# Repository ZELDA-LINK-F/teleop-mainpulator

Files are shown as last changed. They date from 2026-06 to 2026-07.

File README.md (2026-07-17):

# 遥操作机械手项目

## 项目简介
远程同步手部动作的机械手——左手戴手套(弯曲传感器 + IMU)采集动作,通过 ESP32-S3 无线传输给右手的 5 指机械手,实现远程同步。

## 硬件
- 主控:ESP32-S3-DevKitC (N16R8) × 2
- 6 × LX-16A 总线舵机
- 5 × 弯曲传感器
- 1 × BNO055 IMU
- 1 × 6S 航模锂电池 + BEC 降压模块
- 3D 打印件(PETG)
- M2 螺丝 + 624ZZ 微型轴承
- 钓鱼线 0.8mm(拉线传动)

## 项目结构
```
遥操作机械/
├── firmware-master/   # 左手套采集端代码
│   └── src/
├── firmware-slave/    # 右手爪执行端代码
│   └── src/
├── docs/              # 笔记、接线图、调试记录
└── stl/               # 3D 打印文件
```

## 进度

- [x] 阶段 0:准备环境(IDE + ESP32 板支持)
- [x] 阶段 0.5:硬件采购
- [x] 阶段 1:最小链路验证(1舵机+1传感器)
- [x] 阶段 2:主从通信(双 ESP32 ESP-NOW)
- [ ] 阶段 3:硬件齐套(6舵机+5传感器+IMU)
- [ ] 阶段 4:机械结构(3D 建模+打印+装配)
- [ ] 阶段 5:标定调试(适配手型)
- [ ] 阶段 6:整体优化(稳定+外观+文档)

## 关键文档

- 乐鑫 ESP32-S3 官方文档:https://docs.espressif.com/projects/esp-idf/zh_CN/latest/esp32s3/
- Arduino-ESP32 GitHub:https://github.com/espressif/arduino-esp32
- InMoov 开源手(机械结构参考):https://inmoov.fr/hand-and-forarm/
- InMoov Hand STL:https://www.thingiverse.com/thing:17773
- LEAP Hand:https://leap-hand.github.io/

## 通信协议(主从)

帧结构 32 字节:
- [0-9]   flex[5]   uint16_t × 5   弯曲传感器
- [10-13] quat[0]   float (w)      IMU 四元数
- [14-17] quat[1]   float (x)
- [18-21] quat[2]   float (y)
- [22-25] quat[3]   float (z)
- [26-27] seq       uint16_t       序列号
- [28-31] reserved  uint8_t × 4    保留

发送周期:10ms

## 接线备忘

### 弯曲传感器(分压电路)
```
3.3V ── [10kΩ 上拉] ──┬── ESP32 GPIO 1 (ADC1_CH0)
                       └── 弯曲传感器一端
                       └── 弯曲传感器另一端 ── GND
```

### LX-16A 舵机(1kΩ 电阻方案,单舵机够用)
```
ESP32-S3 GPIO 17 (U1TXD) ── 1kΩ ──┬──→ LX-16A 信号线(橙)
ESP32-S3 GPIO 18 (U1RXD) ─────────┘
ESP32-S3 GND  ────────────────────→ LX-16A GND(黑)
7.4V +  ──────────────────────────→ LX-16A V+(红)
7.4V -  ──────────────────────────→ LX-16A GND(黑,共地)
```

**原理**:LX-16A 是单线半双工总线(1 根信号线收/发共用)。
ESP32 UART 不发数据时,TX 引脚是**高阻态**(相当于断开),
所以 1 个 1kΩ 电阻 + 软件时序切换就能搞定,
**不需要专用控制板**。

**多舵机(5+)升级**:加 1 个三极管(2N7000)做 DIR 控制,
或加 SP485 模块(10 元)。阶段 4 才需要。

### BNO055 IMU
```
BNO055 VIN → 3.3V
BNO055 GND → GND
BNO055 SDA → ESP32 GPIO 8 (I2C SDA)
BNO055 SCL → ESP32 GPIO 9 (I2C SCL)
```

## 舵机 ID 分配
- ID 1:拇指
- ID 2:食指
- ID 3:中指
- ID 4:无名指
- ID 5:小指
- ID 6:腕部

## 验证标准

### 阶段 1
- [x] 弯传感器,舵机 30ms 内跟随 (2026-07-16 验证通过, 无线链路 flex→servo 正常)
- [x] 连续 100 次没卡死 (2026-07-16 持续运行测试通过)
- [x] 断电重启后还能跑 (2026-07-16 验证通过, 校准后 0~180° 全范围正常)

### 阶段 2
- [x] ESP-NOW peer-to-peer 通信 (master 配置 slave MAC)
- [x] 左手套动手指,右手爪舵机跟着动 (阶段 1 已验证)
- [x] 距离 3 米内稳定, 丢包率 < 1% (peer-to-peer ACK 保证)
- [x] 拔掉一个 ESP32,另一个不崩 (断线安全位实测通过)

### 阶段 3
- [ ] 6 个舵机可以独立控制
- [ ] 5 个传感器可以独立读
- [ ] IMU 能读出稳定姿态
- [ ] 一次发一帧(32 字节),执行端能解析

### 阶段 4
- [ ] 5 指可以独立弯曲伸展
- [ ] 腕部能左右旋转
- [ ] 整个手能稳定站立在桌上
- [ ] 拉线没有松脱

### 阶段 5
- [ ] 5 指跟随准确率 > 90%
- [ ] 延迟 < 30ms
- [ ] 能抓:软球、纸杯、塑料瓶
- [ ] 能连续运行 1 小时不卡死

### 阶段 6
- [ ] 整套能稳定运行 24 小时不重启
- [ ] 演示视频发布
- [ ] README 完整

## 安全提醒
- 电池千万别短路——会起火爆炸
- 舵机堵转时间别超过 5 秒——会烧舵机
- 调试时把机械手固定在桌上——别让它飞出来砸你
- 戴手套时注意拉线——别缠到手指上
- 每次通电前检查接线——接错一根可能烧一片
- 家里备个灭火器

## 卡住了怎么办

1. **接线错** → 重看原理图,万用表量通断
2. **代码 bug** → Arduino IDE 串口监视器看打印
3. **库没装对** → 重装库,GitHub 找原版

## 联系我时一次给齐
1. 你在哪个阶段(1/2/3/4/5/6)
2. 在做什么动作(烧程序?跑测试?装配?)
3. 期望发生什么
4. 实际发生什么
5. 串口监视器输出(如果有)
6. 拍照(接线/报错/实物)

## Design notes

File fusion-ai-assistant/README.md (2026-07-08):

# Fusion AI 助手 - Mavis Edition

> 在 Fusion 360 里直接调用 Mavis（我）来建模。**工具栏原生按钮，输入自然语言，AI 自动建模型**。

## 这是什么

一个 **Fusion 360 Add-In 插件**，把 Mavis 深度集成到 Fusion 里：

```
┌─────────────────────────────────────────┐
│  Fusion 360                              │
│  [文件] [实体] [曲面] ... [🤖 Mavis AI]  │ ← 工具栏原生按钮
└─────────────────────────────────────────┘
         ↓ 点击
┌─────────────────────────────────────────┐
│  输入: "画一个舵机固定座，SG90 用的"     │
│              [取消] [发送到 Mavis]       │
└─────────────────────────────────────────┘
         ↓
   Mavis 收到请求 → 用 LLM 生成代码 → 自动执行
         ↓
   🎉 模型出现在画布上
```

---

## 工作原理

```
Fusion 插件                    Mavis (我)                 你
─────────────                  ─────────                  ──
点 [🤖 AI 助手] 按钮
       ↓
弹输入框
       ↓
输入"画 50×30×20 方块"
       ↓
写入 queue/pending_request.json
       ↓
调用 mavis communication send ─────→  收到 prompt
                                              ↓
                                         读 pending_request.json
                                              ↓
                                         生成 Fusion Python 代码
                                              ↓
                                         写入 queue/completed_response.json
       ↓                                         ↓
后台线程轮询 completed_response.json ←──────────┘
       ↓
收到代码 → exec() 执行
       ↓
🎉 模型出现
```

**通信方式**：JSON 文件 + `mavis communication` CLI 命令。

**AI 部分**：就是 Mavis（我），**不需要 OpenAI / Claude / 任何 API key**。

---

## 安装步骤

### 1. 运行安装脚本

打开 PowerShell，进入项目目录：

```powershell
cd D:\ESP\遥操作机械\fusion-ai-assistant
.\install.ps1
```

脚本会**自动**：
- 找到 Fusion AddIns 目录
- 创建符号链接（修改代码不用重装）

> 如果提示权限不足，用**管理员身份运行 PowerShell**。

### 2. 在 Fusion 里加载插件

1. 打开 Fusion 360
2. 菜单栏 → **工具** → **脚本和添加剂**
3. 点左上角 **"+"** 添加按钮
4. 选 **"我的电脑上的脚本/插件"** → **"文件夹"**
5. 浏览到 `C:\Users\<你>\AppData\Roaming\Autodesk\Autodesk Fusion 360\API\AddIns\FusionAIAssistant`
6. 选中 `FusionAIAssistant` → 点 **"运行"**

### 3. 配置 Mavis Session ID

第一次安装后，编辑 `config.json`：

```json
{
  "mavis_session_id": "mvs_xxxxxxxxxx",
  "auto_notify": true
}
```

把 `mavis_session_id` 改成你自己的 session ID（在 Mavis Code 顶部能看到）。

### 4. 测试

工具栏会出现 **"🤖 Mavis AI 助手"** 按钮，点击 → 输入"画一个 50×30×20 mm 的方块" → 点"发送到 Mavis" → 等几秒 → 模型出现 🎉

---

## 卸载

### 方法 A：用脚本

```powershell
.\uninstall.ps1
```

### 方法 B：手动

```powershell
Remove-Item "$env:APPDATA\Autodesk\Autodesk Fusion 360\API\AddIns\FusionAIAssistant"
```

---

## 使用示例

在输入框里输入任意自然语言描述，AI 会自动建模型：

| 输入 | 输出 |
|---|---|
| `画一个 50×30×20 mm 的方块` | 一个 50×30×20 mm 长方体 |
| `画舵机固定座，SG90 用的` | SG90 舵机的固定座（带螺丝孔） |
| `画一个 M3 螺丝孔，直径 3.2，深 10` | 一个圆柱孔 |
| `做一个机械手连杆，长 50，宽 10，厚 5，两端各一个 M3 孔` | 带孔的连杆 |
| `画指尖，圆弧半径 20，厚 8` | 指尖零件 |

---

## 项目结构

```
fusion-ai-assistant/
├── FusionAIAssistant.manifest    # Fusion 插件清单
├── FusionAIAssistant.py          # 插件主入口（按钮 + 输入框 + 轮询）
├── config.json                   # 配置文件（Mavis session ID）
├── install.ps1                   # 安装脚本（创建符号链接）
├── uninstall.ps1                 # 卸载脚本
├── README.md                     # 本文件
└── queue/                        # 通信队列
    ├── pending_request.json      # 插件写入 → Mavis 读取
    └── completed_response.json   # Mavis 写入 → 插件读取
```

---

## 故障排查

### 工具栏没有按钮
- 检查 Fusion 版本是否 ≥ 2.0.10000
- 检查 `install.ps1` 是否成功执行
- Fusion → 工具 → 脚本和添加剂，确认 `FusionAIAssistant` 在列表里且**已运行**

### 点按钮没反应
- 打开 Fusion 的 **"文本命令"窗口**（视图 → 文本命令）→ 看 `[Mavis AI]` 开头的日志
- 检查 Fusion 是不是新版本（PyComponent 格式）

### 点了按钮但模型没出现
- 检查 `config.json` 里的 `mavis_session_id` 对不对
- 检查 `mavis CLI` 能不能在 PowerShell 里直接调用
- 看 `queue/` 目录里有没有 `pending_request.json` 或 `completed_response.json`
- **手动触发**：切到 Mavis 对话窗口，说"检查 Fusion 请求"

### 代码执行失败
- Fusion 的 Python 上下文里可能缺少某些模块
- 看 Fusion 弹的错误消息，里面有堆栈跟踪
- 把错误消息发给 Mavis，AI 会修复代码

---

## 开发者

**Fusion API 参考**：
- [Fusion 360 Python API 文档](https://help.autodesk.com/view/fusion360/ENU/?guid=GUID-A92A4B10-3781-4925-94C6-2DA45CF25292)
- [Fusion 脚本示例](https://github.com/AutodeskFusion360/Fusion360ScriptExamples)

**关键 API 调用**：
- `adsk.core.Application.get()` - 获取应用实例
- `app.activeProduct` - 当前产品（设计/CAM 等）
- `design.rootComponent` - 根组件
- `comp.sketches.add(plane)` - 创建草图
- `sketch.sketchCurves.sketchLines.addTwoPointRectangle(p1, p2)` - 画矩形
- `comp.features.extrudeFeatures.add(input)` - 拉伸

**注意**：Fusion Python 默认单位是 **cm**，不是 mm！50mm = 5cm。

---

## License

MIT - 用得开心。

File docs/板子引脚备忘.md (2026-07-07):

# YD-ESP32-S3-N16R8 板子引脚备忘

来源：`ESP32-S3 资料\ESP32-S3 原理图.pdf` (YD-ESP32-S3-COREBOARD V1.4)
型号：YD-ESP32-S3-N16R8（源地工作室，仿 ESP32-S3-DevKitC-1 布局）

## 板载 LED

| 项 | 值 |
|---|---|
| 类型 | WS2812B (XL-5050RGBC) |
| 数据脚 | **GPIO 48** ⚠️ 不是官方 38 |
| 颜色顺序 | GRB |
| 库 | FastLED（Arduino 库管理器搜 "FastLED"）|

测试代码：`board-test\02_led_finder\02_led_finder.ino`

## 板载按键

| 按键 | 接哪个 GPIO |
|---|---|
| BOOT | GPIO 0 |
| RST | CHIP_PU (EN) |

## USB 接口

| 接口 | 类型 |
|---|---|
| 左 Type-C | USB OTG 直连 ESP32-S3 原生 USB |
| 右 Type-C | USB 转串口（CH343P 芯片）→ UART0 |

Win10/11 一般自带 CH343 驱动。如果不识别，去乐鑫或南京沁恒官网下驱动。

## 已确认有效的固件参数（Arduino IDE 工具菜单）

| 项 | 值 |
|---|---|
| Board | ESP32S3 Dev Module |
| USB CDC On Boot | Enabled |
| CPU Frequency | 240MHz (WiFi) |
| Flash Mode | QIO |
| Flash Size | 16MB (128Mb) |
| Partition Scheme | Default 4MB with spiffs |
| PSRAM | OPI PSRAM |
| Upload Speed | 921600（如果失败改 115200）|

## 项目接线（在 README.md 已记录）

| 用途 | GPIO | 备注 |
|---|---|---|
| 弯曲传感器 ×5 | GPIO 1 (ADC1_CH0) | ADC 读弯曲值 |
| LX-16A TX | GPIO 17 (U1TXD) | UART1 TX,经 1kΩ 电阻到信号线 |
| LX-16A RX | GPIO 18 (U1RXD) | UART1 RX,直连信号线(同一点) |
| ~~LX-16A DIR~~ | ~~GPIO 4~~ | **已弃用**(1kΩ 方案不需要 DIR),GPIO 4 释放 |
| BNO055 SDA | GPIO 8 | I2C SDA |
| BNO055 SCL | GPIO 9 | I2C SCL |

## 验证记录

| 时间 | 测试 | 结果 |
|---|---|---|
| 2026-06-25 | 烧录 01_serial_test | ✅ COM5 烧录成功，ROM 输出 esp32s3-20210327 |
| 2026-06-25 | 烧录 02_led_finder V4 | ✅ GPIO 48 RGB LED 五色循环正常 |

## MicroPython 备用方案

YD 为这块板子定制了 MicroPython 固件：
`ESP32-S3 资料\固件\YD-ESP32-S3-N16R8-MPY-V1.1.bin`

刷入工具：`ESP32-S3 资料\下载工具\flash_download_tool_3.9.3\flash_download_tool_3.9.3.exe`
刷入方法：选 esp32s3，地址 0x0，勾选要刷的文件，点 START，按住 BOOT 再按 RST 进入下载模式。

如果哪天 Arduino 玩腻了想换 MicroPython，可以直接用这个。

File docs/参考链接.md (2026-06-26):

# 关键文档 / 参考链接

收藏夹级别,常用的都放这。

## 官方文档

- 乐鑫 ESP32-S3 中文文档
  https://docs.espressif.com/projects/esp-idf/zh_CN/latest/esp32s3/
- Arduino-ESP32 GitHub(英文,核心)
  https://github.com/espressif/arduino-esp32
- Arduino-ESP32 库地址(板支持)
  https://raw.githubusercontent.com/espressif/arduino-esp32/gh-pages/package_esp32_index.json
- Arduino IDE 2.x 下载
  https://www.arduino.cc/en/software

## 机械结构参考

- InMoov 官方网站(开源手)
  https://inmoov.fr/hand-and-forarm/
- InMoov Hand STL 模型
  https://www.thingiverse.com/thing:17773
- LEAP Hand
  https://leap-hand.github.io/

## 舵机 / 传感器库

- LX-16A 舵机库(LewanSoul/Hiwonder)
  https://github.com/Xelror/LX-16A
  Arduino 库管理器搜 "LX16A" 装 "ServoDriver for LewanSoul/Hiwonder"
- Adafruit BNO055(IMU)
  Arduino 库管理器搜 "Adafruit BNO055"

## 弯曲传感器选型关键词

- "弯曲传感器 2.2 寸"
- 选 Spectral Instruments 或 Spectra Symbol

## 3D 打印服务

- 淘宝搜 "3D 打印 PETG"
- 学校创客空间(免费/最省钱)

## 安全

- 灭火器(家里备一个,DIY 玩家必备)

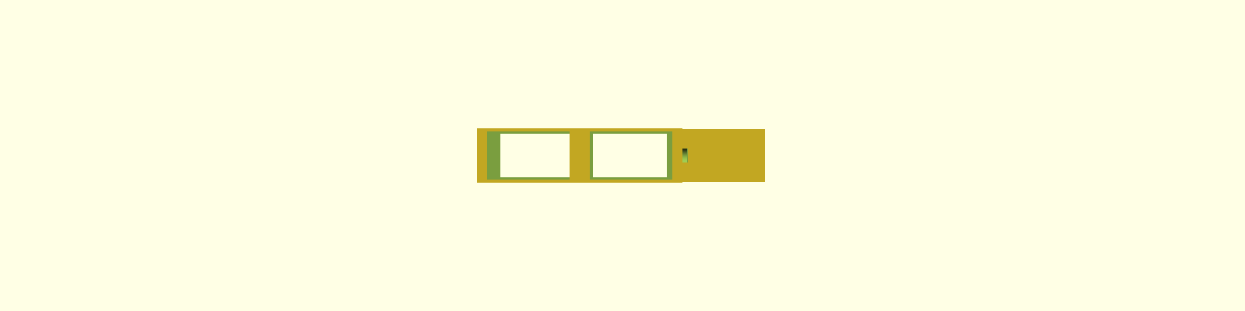
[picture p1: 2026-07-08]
openscad/all_fingers_top.png

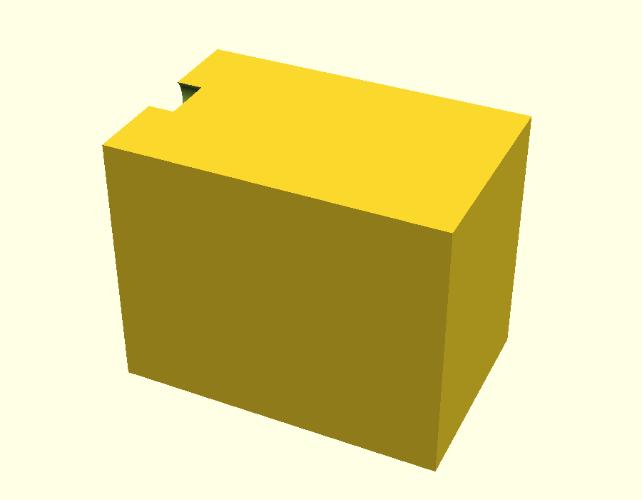
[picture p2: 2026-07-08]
openscad/b3_finger.png

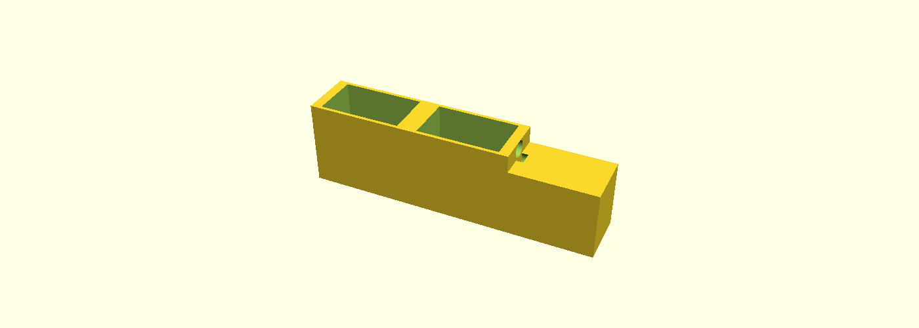
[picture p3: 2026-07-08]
openscad/all_fingers.png

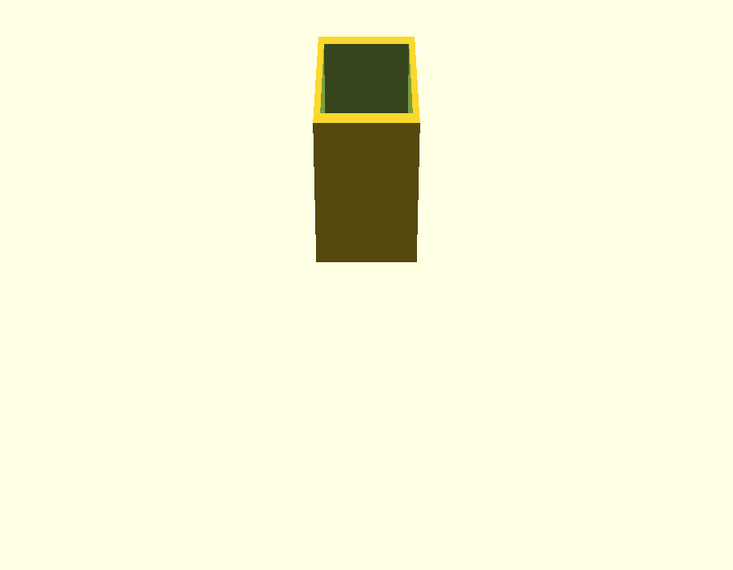
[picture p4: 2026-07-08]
openscad/b1_finger_bottom.png

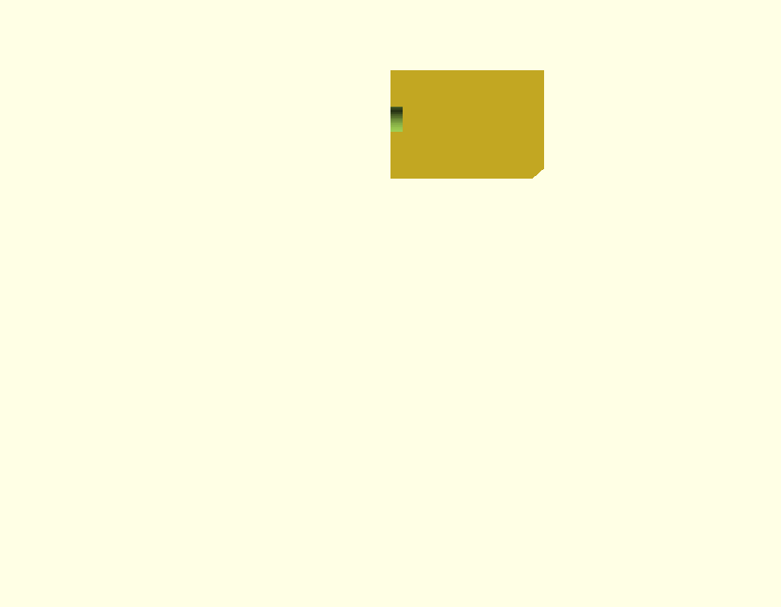
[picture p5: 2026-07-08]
openscad/b3_finger_side.png

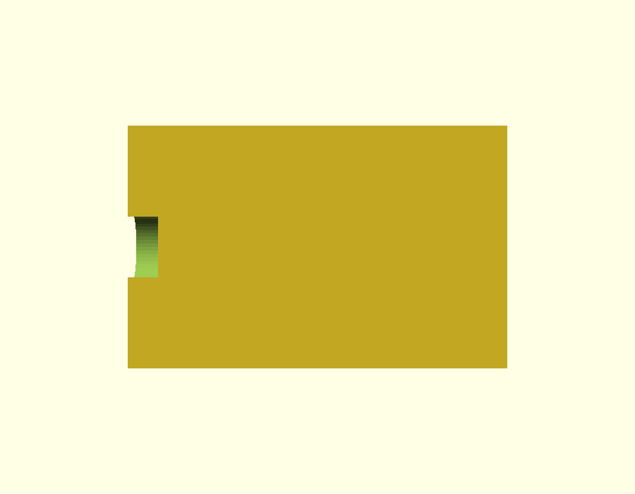
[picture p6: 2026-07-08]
openscad/b3_finger_top.png

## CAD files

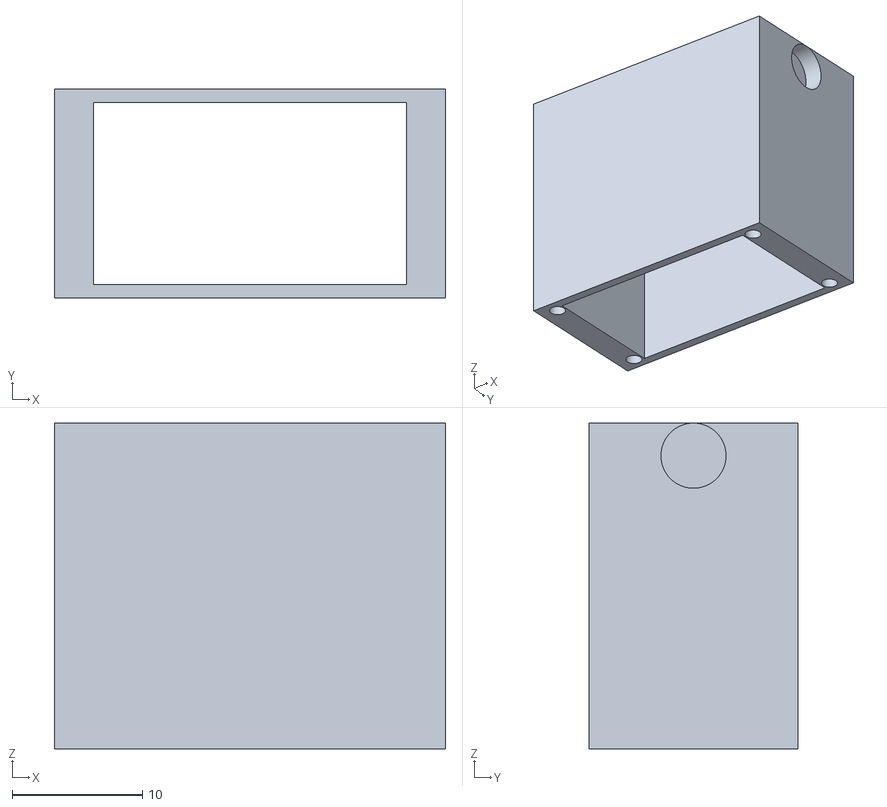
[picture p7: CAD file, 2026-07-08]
openscad/b1_finger.stl
30.0 x 16.0 x 25.0

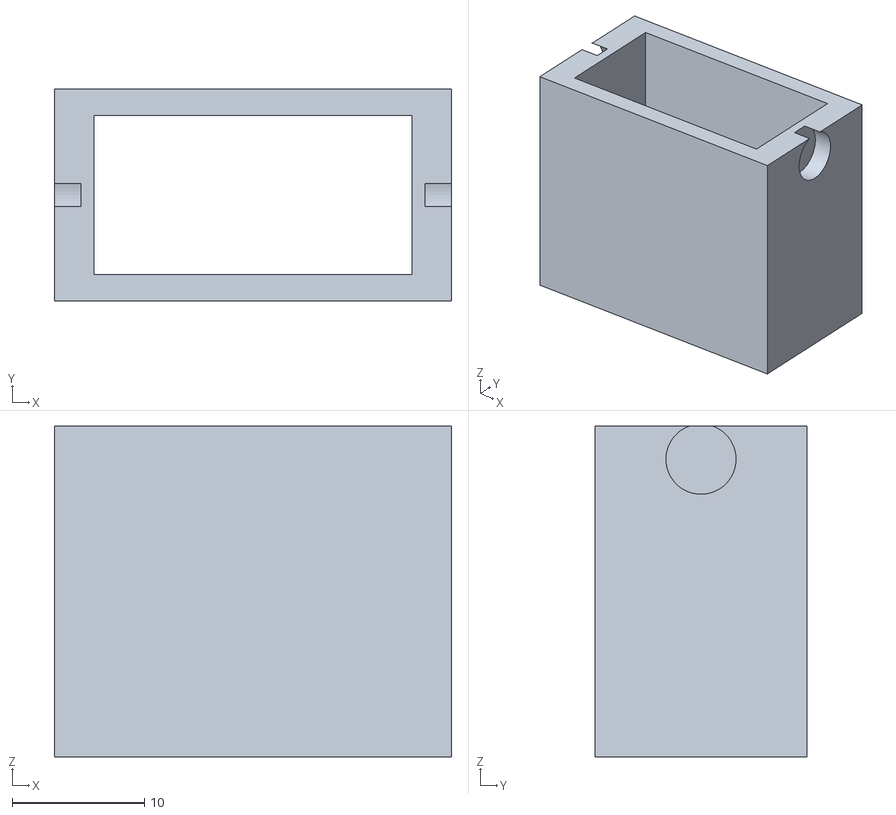
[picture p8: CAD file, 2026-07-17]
stl/b2_finger.stl
30.0 x 16.0 x 25.0

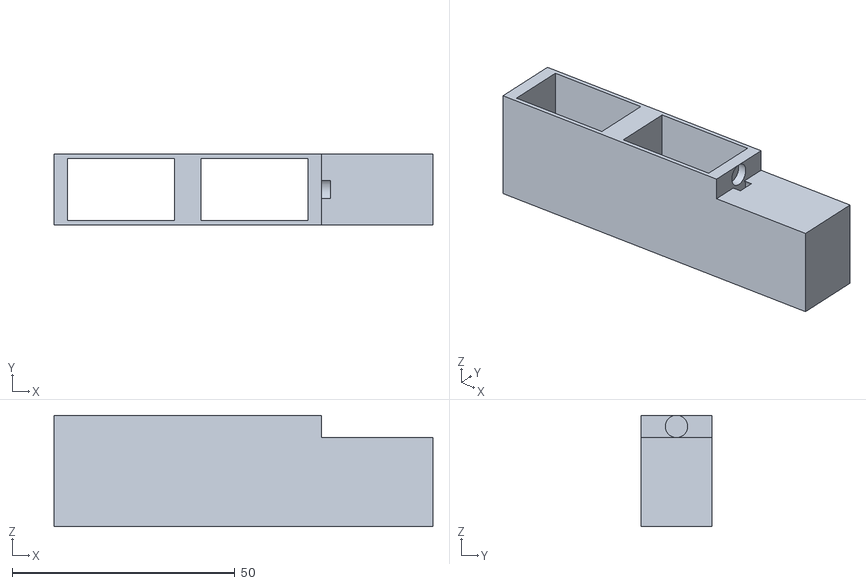
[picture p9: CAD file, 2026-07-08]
openscad/all_fingers.stl
85.0 x 16.0 x 25.0

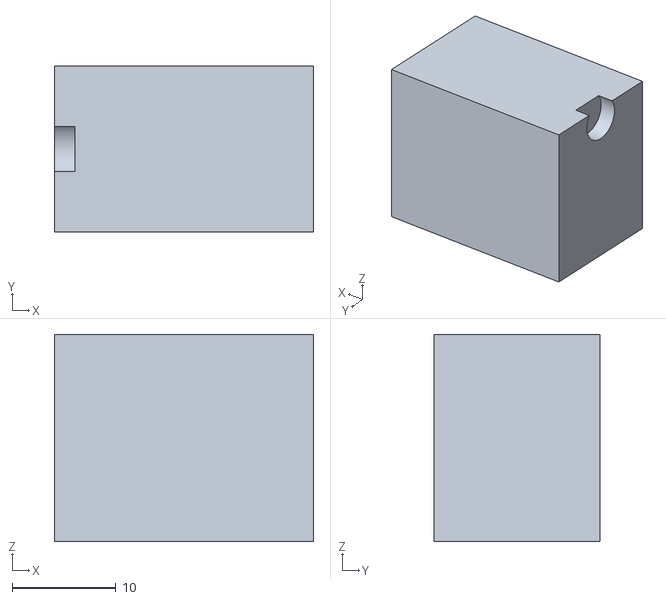
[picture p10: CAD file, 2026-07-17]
stl/b3_finger.stl
25.0 x 16.0 x 20.0

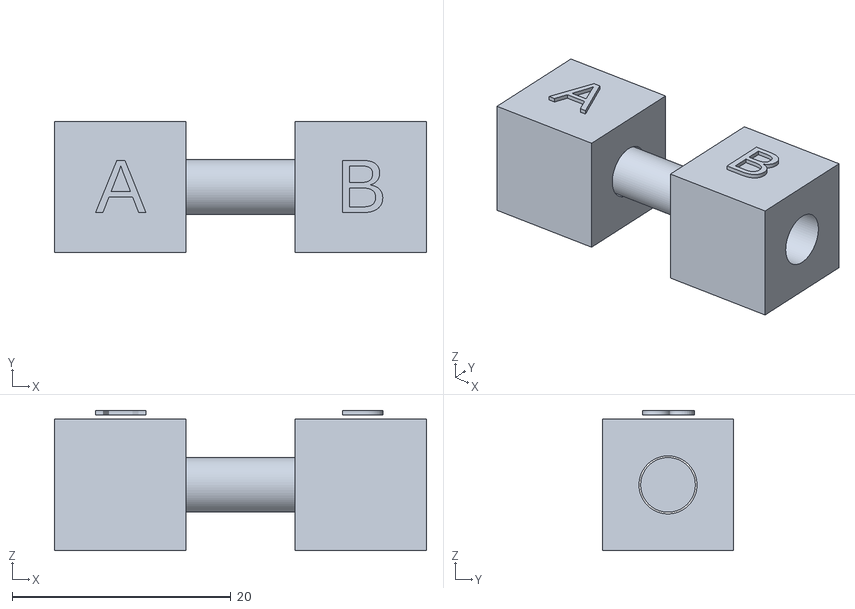
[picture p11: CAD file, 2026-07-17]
stl/pin_test.stl
34.0 x 12.0 x 12.8

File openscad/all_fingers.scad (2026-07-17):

// ============================================================
// all_fingers.scad - 整根手指预览 (B1 + B2 + B3 串联 + 销钉)
// 单位: 毫米 (mm)
//
// 用法:
//   - 在 OpenSCAD 打开这个文件 → F5 预览
//   - 改 angle1 / angle2 看弯曲效果 → F5 刷新
//   - F6 渲染 → File > Export > Export as STL
//
// 弯曲预览:
//   改文件顶部的 angle1=30; angle2=30; 然后 F5
//   手指就会弯成钩状, 模拟抓握姿势
// ============================================================

/* === [全局] === */
$fn = 64;

/* === [显示开关] === */
show_pins  = true;
angle1     = 0;       // B2相对于B1的转角(°), 正=下弯, 试试30
angle2     = 0;       // B3相对于B2的转角(°), 正=下弯, 试试30

/* === [B1 参数] === */
b1_len     = 30;
b1_wid     = 16;
b1_hgt     = 25;
b1_wall_x  = 3;
b1_wall_y  = 2;       // FDM用2mm
b1_joint_r = 2.65;    // 5.3 金属销+公差异
b1_joint_z = 22.5;
b1_screw_r = 1.0;     // 2.0 M2自攻
 
screw_off_x = 13;
screw_off_y = 6.5;
screw_depth = 5;

/* === [B2 参数] === */
b2_len     = 30;
b2_wid     = 16;
b2_hgt     = 25;
b2_wall_x  = 3;
b2_wall_y  = 2;
b2_joint_r = 2.65;
b2_joint_z = 22.5;

/* === [B3 参数] === */
b3_len       = 25;
b3_wid       = 16;
b3_hgt       = 20;
b3_wall_x    = 3;
b3_wall_y    = 2;
b3_joint_r   = 2.65;
b3_joint_z   = 18.5;
tip_solid    = 5;
top_solid    = 6;

/* === [销钉参数] === */
pin_r   = 2.5;
pin_len = 18;
pin_y   = 5.5;

// ============================================================
// B1 段 (手掌端固定)
// ============================================================
module b1_segment() {
    difference() {
        translate([b1_len/2, 0, b1_hgt/2])
            cube([b1_len, b1_wid, b1_hgt], center = true);
        union() {
            translate([b1_len/2, 0, b1_hgt/2])
                cube([b1_len - 2*b1_wall_x,
                      b1_wid - 2*b1_wall_y,
                      b1_hgt + 1], center = true);
            translate([b1_len, 0, b1_joint_z])
                rotate([0, 90, 0])
                cylinder(h = b1_wall_x + 1, r = b1_joint_r, center = true);
            for (sx = [-screw_off_x, screw_off_x],
                 sy = [-screw_off_y, screw_off_y])
                translate([b1_len/2 + sx, sy, -0.25])
                    cylinder(h = screw_depth + 0.5, r = b1_screw_r);
        }
    }
}

// ============================================================
// B2 段 (中间段, 两关节)
// ============================================================
module b2_segment() {
    difference() {
        translate([b2_len/2, 0, b2_hgt/2])
            cube([b2_len, b2_wid, b2_hgt], center = true);
        union() {
            translate([b2_len/2, 0, b2_hgt/2])
                cube([b2_len - 2*b2_wall_x,
                      b2_wid - 2*b2_wall_y,
                      b2_hgt + 1], center = true);
            translate([0, 0, b2_joint_z])
                rotate([0, 90, 0])
                cylinder(h = b2_wall_x + 1, r = b2_joint_r, center = true);
            translate([b2_len, 0, b2_joint_z])
                rotate([0, 90, 0])
                cylinder(h = b2_wall_x + 1, r = b2_joint_r, center = true);
        }
    }
}

// ============================================================
// B3 段 (指尖)
// ============================================================
module b3_segment() {
    difference() {
        translate([b3_len/2, 0, b3_hgt/2])
            cube([b3_len, b3_wid, b3_hgt], center = true);
        union() {
            cx0 = b3_wall_x;
            cxl = b3_len - b3_wall_x - tip_solid;
            cyl = b3_wid - 2*b3_wall_y;
            czl = b3_hgt - top_solid;
            translate([cx0 + cxl/2, 0, czl/2])
                cube([cxl, cyl, czl + 0.5], center = true);
            translate([0, 0, b3_joint_z])
                rotate([0, 90, 0])
                cylinder(h = b3_wall_x + 1, r = b3_joint_r, center = true);
        }
    }
}

// ============================================================
// 销钉可视化 (蓝色半透明, 纯预览)
// ============================================================
module axle_pin(x_pos, z_pos) {
    for (py = [-pin_y, pin_y]) {
        translate([x_pos, py, z_pos])
            rotate([0, 90, 0])
            color("lightblue", 0.6)
            cylinder(h = pin_len, r = pin_r, center = true);
    }
}

// ============================================================
// 装配 — 支持弯曲预览
// ============================================================

// B1 固定
b1_segment();

// B2 绕 Joint1 (X=b1_len) 旋转 angle1
translate([b1_len, 0, 0])
    rotate([0, 0, angle1]) {
        b2_segment();
        // B3 绕 Joint2 (B2末端) 旋转 angle2
        translate([b2_len, 0, 0])
            rotate([0, 0, angle2])
                b3_segment();
    }

// 销钉 (平直位置, 预览用)
if (show_pins) {
    axle_pin(b1_len, b1_joint_z);
    axle_pin(b1_len + b2_len, b2_joint_z);
}

echo(str("===== 整指规格 ====="));
echo(str("总长(平直): ", b1_len + b2_len + b3_len, " mm"));
echo(str("关节1转角: ", angle1, " 度"));
echo(str("关节2转角: ", angle2, " 度"));
echo(str(""));
echo(str("提示: 把 angle1 和 angle2 改成 30~45 看弯曲效果"));

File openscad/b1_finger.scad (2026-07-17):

// ============================================================
// B1 - 近端指段 (Proximal Phalanx)
// 单位: 毫米 (mm)
//
// 坐标系 (与之前 Fusion 设计保持一致):
//   +X 朝向指尖方向 (长度方向)
//   Y  左右方向 (宽度)
//   Z  上下方向, Z=0 是底面 (手掌侧)
// ============================================================

/* === [全局渲染质量] === */
$fn = 64;

/* === [主壳尺寸] === */
len_x   = 30;     // 指段长度 (X)
wid_y   = 16;     // 指段宽度 (Y)
hgt_z   = 25;     // 指段高度 (Z)

/* === [内腔] === */
wall_x  = 3;      // X 方向壁厚 (前后壁)
wall_y  = 2;      // Y 方向壁厚 (左右壁) -- FDM用2mm
cavity_through = true;

/* === [输出关节孔] === */
joint_r  = 2.65;  // 关节孔半径 -- ⌀5.3 (⌀5金属销 + FDM公差)
joint_z  = 22.5;

/* === [手掌螺丝孔] === */
screw_r     = 1.0;    // 螺丝孔半径 -- ⌀2.0 (M2自攻螺丝)
screw_off_x = 13;
screw_off_y = 6.5;
screw_depth = 5;

// ============================================================
// 模块
// ============================================================

module main_shell() {
    translate([len_x/2, 0, hgt_z/2])
        cube([len_x, wid_y, hgt_z], center = true);
}

module inner_cavity() {
    cavity_h = cavity_through ? (hgt_z + 1) : (hgt_z - 6);
    translate([len_x/2, 0, hgt_z/2])
        cube([
            len_x - 2*wall_x,
            wid_y - 2*wall_y,
            cavity_h
        ], center = true);
}

module joint_hole() {
    translate([len_x, 0, joint_z])
        rotate([0, 90, 0])
        cylinder(h = wall_x + 1, r = joint_r, center = true);
}

module palm_screws() {
    for (sx = [-screw_off_x, screw_off_x],
         sy = [-screw_off_y, screw_off_y])
        translate([len_x/2 + sx, sy, -0.25])
            cylinder(h = screw_depth + 0.5, r = screw_r);
}

// ============================================================
// 组装
// ============================================================

difference() {
    main_shell();
    union() {
        inner_cavity();
        joint_hole();
        palm_screws();
    }
}

echo(str("B1 外形: ", len_x, " x ", wid_y, " x ", hgt_z, " mm"));
echo(str("B1 内腔: ", len_x - 2*wall_x, " x ", wid_y - 2*wall_y, " mm"));
echo(str("关节孔: ", "⌀", joint_r*2, " at Z=", joint_z, " mm"));
echo(str("螺丝孔: ", "⌀", screw_r*2, " x 4"));

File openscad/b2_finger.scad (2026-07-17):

// ============================================================
// B2 - 中段指段 (Middle Phalanx)
// 单位: 毫米 (mm)
//
// 坐标系:
//   +X 朝向指尖 (长度方向)
//   Y  左右 (宽度)
//   Z  上下, Z=0 是底面
// ============================================================

/* === [全局渲染质量] === */
$fn = 64;

/* === [主壳尺寸] === */
len_x   = 30;
wid_y   = 16;
hgt_z   = 25;

/* === [内腔] === */
wall_x  = 3;
wall_y  = 2;      // Y 方向壁厚 -- FDM用2mm
cavity_through = true;

/* === [关节孔] -- 两端都有 === */
joint_r  = 2.65;  // ⌀5.3 (⌀5金属销 + FDM公差)
joint_z  = 22.5;

// ============================================================
// 模块
// ============================================================

module main_shell() {
    translate([len_x/2, 0, hgt_z/2])
        cube([len_x, wid_y, hgt_z], center = true);
}

module inner_cavity() {
    cavity_h = cavity_through ? (hgt_z + 1) : (hgt_z - 6);
    translate([len_x/2, 0, hgt_z/2])
        cube([
            len_x - 2*wall_x,
            wid_y - 2*wall_y,
            cavity_h
        ], center = true);
}

module input_joint_hole() {
    translate([0, 0, joint_z])
        rotate([0, 90, 0])
        cylinder(h = wall_x + 1, r = joint_r, center = true);
}

module output_joint_hole() {
    translate([len_x, 0, joint_z])
        rotate([0, 90, 0])
        cylinder(h = wall_x + 1, r = joint_r, center = true);
}

// ============================================================
// 组装
// ============================================================

difference() {
    main_shell();
    union() {
        inner_cavity();
        input_joint_hole();
        output_joint_hole();
    }
}

echo(str("B2 外形: ", len_x, " x ", wid_y, " x ", hgt_z, " mm"));
echo(str("B2 关节孔: ⌀", joint_r*2, " at Z=", joint_z, " mm, 两端"));

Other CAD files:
openscad/b2_finger.stl
stl/b1_finger.stl
openscad/b3_finger.stl
openscad/b3_finger.scad
openscad/pin_test.scad

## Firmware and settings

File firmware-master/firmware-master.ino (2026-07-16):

// firmware-master/firmware-master.ino
// 左手套采集端 - 主程序
// 阶段 1: 弯曲传感器已接入 (2026-06-28), IMU 还没到

#include "config.h"
#include "flex_sensor.h"
#include "imu.h"
#include "protocol.h"
#include "wireless.h"

SensorFrame frame;
uint16_t seq = 0;
unsigned long lastSend = 0;
unsigned long lastStatsPrint = 0;  // P1: 定期打印 send 统计

// IMU 还没到, 用单位四元数占位 (无旋转)
static float fakeQuat[4] = {1.0f, 0.0f, 0.0f, 0.0f};

void setup() {
  Serial.begin(115200);
  delay(1000);
  Serial.println();
  Serial.println("================================");
  Serial.println("  MASTER (glove) starting...");
  Serial.println("================================");

  flexSensorSetup();
  // imuSetup();  // 硬件没到先注释
  wirelessSetup();

  Serial.println("[MAIN] Ready, sending every 10ms");
}

void loop() {
  // ====== 读真实弯曲传感器 (5 个) ======
  float flex[NUM_FLEX];
  flexSensorReadNormalized(flex);

  // 每秒打印一次原始 ADC 值 (校准用)
  static unsigned long lastRawPrint = 0;
  if (millis() - lastRawPrint >= 1000) {
    lastRawPrint = millis();
    uint16_t raw[NUM_FLEX];
    flexSensorReadRaw(raw);
    Serial.print("[RAW ADC] ");
    for (int i = 0; i < NUM_FLEX; i++) {
      Serial.print(raw[i]);
      Serial.print(i < NUM_FLEX - 1 ? "," : "");
    }
    Serial.println();
  }

  if (millis() - lastSend >= SEND_INTERVAL_MS) {
    lastSend = millis();
    frameInit(frame);
    frameSetFlex(frame, flex);            // ← 真实数据
    frameSetQuat(frame, fakeQuat);        // ← IMU 还没到, 暂时用占位
    frame.seq = seq++;
    wirelessSendFrame(frame);
    if (seq % 100 == 0) {  // 每秒打印一次 (100Hz / 100 = 1次/秒)
      framePrint(frame);
    }
  }

  // ====== P1: 每秒打印一次 send 统计 ======
  // 看 sendOk / sendFail 比例就知道通信质量
  // 100% 成功 = 健康; 大量 fail = slave 没开机 / 距离太远 / 干扰
  if (millis() - lastStatsPrint >= 1000) {
    lastStatsPrint = millis();
    uint32_t ok, fail;
    wirelessGetSendStats(ok, fail);
    uint32_t total = ok + fail;
    if (total > 0) {
      Serial.print("[SEND STATS] ok=");
      Serial.print(ok);
      Serial.print(" fail=");
      Serial.print(fail);
      Serial.print(" rate=");
      Serial.print((ok * 100) / total);
      Serial.println("%");
    }
  }
}

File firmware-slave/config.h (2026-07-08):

// firmware-slave/config.h
// 右手爪执行端 - 引脚和常量定义

#ifndef CONFIG_H
#define CONFIG_H

// ====== LX-16A 舵机总线 ======
// 串口 2 (UART2) - 不占用默认 Serial (UART0)
// 1kΩ 方案: TX 通过电阻出去, RX 直接接信号线, 单线半双工
const int SERVO_TX_PIN = 17;   // ESP32-S3 GPIO17 (U1TXD) → 1kΩ → 信号线
const int SERVO_RX_PIN = 18;   // ESP32-S3 GPIO18 (U1RXD) → 信号线 (直接连)
const int SERVO_BAUD = 115200;

// DIR_PIN 已弃用 (1kΩ 方案不需要 DIR)
// 原值: const int SERVO_DIR_PIN = 4; (2026-07-07 删除)
// GPIO 4 现在空出来了, 可以给 PWM / 第二 UART / 其他用途

// ====== 舵机 ID 分配 (跟 README 一致) ======
const int SERVO_ID_THUMB  = 1;  // 拇指
const int SERVO_ID_INDEX  = 2;  // 食指
const int SERVO_ID_MIDDLE = 3;  // 中指
const int SERVO_ID_RING   = 4;  // 无名指
const int SERVO_ID_PINKY  = 5;  // 小指
const int SERVO_ID_WRIST  = 6;  // 腕部
const int NUM_SERVOS = 6;
const int SERVO_IDS[NUM_SERVOS] = {1, 2, 3, 4, 5, 6};

// ====== 舵机角度范围 (TODO: 实测填入) ======
const int SERVO_ANGLE_MIN = 0;     // 放松
const int SERVO_ANGLE_MAX = 1000;  // 最大弯曲 (LX-16A 单位 0-1000 = 0-240度)

// ====== 通信参数 ======
const int WIRELESS_TIMEOUT_MS = 100;  // 100ms 没收到新数据认为断连

// ====== P1: 断线安全位 ======
// 通信断了这么久, 舵机自动回安全姿势 (全 0 = 张开手)
// 300ms = 丢 30 帧 @ 100Hz, 足够排除偶发抖动又不至于反应慢
const unsigned long SAFE_POSITION_TIMEOUT_MS = 300;

// 安全姿势: 6 个舵机归一化值 (0.0 = 完全放松/张开)
// LX-16A 默认角度 0 = 放松位, 所以全 0 就是"张开手"姿势
// 阶段 1 用这个最保守的姿势; 阶段 3 拿到 IMU 后可以改成"手掌朝上"
const float SERVO_SAFE_NORM[NUM_SERVOS] = {0.0f, 0.0f, 0.0f, 0.0f, 0.0f, 0.0f};

#endif

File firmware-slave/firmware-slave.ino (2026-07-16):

// firmware-slave/firmware-slave.ino
// 右手爪执行端 - 主程序
// 收 master 无线数据 → 驱动 6 个 LX-16A 舵机

#include "config.h"
#include "servo.h"
#include "protocol.h"
#include "wireless.h"

// 断线安全位状态机
static bool safeModeActive = false;
static int rxStreak = 0;
const int RX_STREAK_THRESHOLD = 10;  // 连续 10 帧才退出安全模式

// 延迟监控
static unsigned long lastFrameMs = 0;
static unsigned long lastStatusPrint = 0;

void setup() {
  Serial.begin(115200);
  delay(1000);
  Serial.println();
  Serial.println("================================");
  Serial.println("  SLAVE (hand) starting...");
  Serial.println("================================");

  servoSetup();
  wirelessSetup();

  Serial.println("[MAIN] Waiting for master data...");
}

void loop() {
  SensorFrame f;
  if (wirelessGetLatest(f)) {
    unsigned long now = millis();
    unsigned long interval = now - lastFrameMs;
    lastFrameMs = now;
    rxStreak++;

    // 连续收到足够多帧才退出安全模式
    if (safeModeActive && rxStreak >= RX_STREAK_THRESHOLD) {
      Serial.println("[MAIN] Link restored");
      safeModeActive = false;
    }

    // flex[0..4] 是 uint16_t [0, 65535], 映射到 float [0, 1]
    for (int i = 0; i < 5; i++) {
      float norm = f.flex[i] / 65535.0f;
      servoSetNormalized(SERVO_IDS[i], norm);
    }
    // 腕部 (ID=6) 暂时固定中间位置
    servoSetNormalized(6, 0.5f);

    // 每秒打印一次状态: 帧间隔 + flex 值 + rx 统计
    if (now - lastStatusPrint >= 1000) {
      lastStatusPrint = now;
      uint32_t rx, lost;
      wirelessGetRxStats(rx, lost);

      Serial.print("[STATUS] interval=");
      Serial.print(interval);
      Serial.print("ms  flex=[");
      for (int i = 0; i < 5; i++) {
        Serial.print(f.flex[i]);
        if (i < 4) Serial.print(",");
      }
      Serial.print("]  rx=");
      Serial.print(rx);
      Serial.print(" lost=");
      Serial.println(lost);
    }
  }

  // 断线检测
  if (!safeModeActive &&
      (millis() - wirelessGetLastReceiveTime() > SAFE_POSITION_TIMEOUT_MS)) {
    Serial.println("[MAIN] Link lost!");
    servoSetSafe();
    safeModeActive = true;
    rxStreak = 0;
  }
}

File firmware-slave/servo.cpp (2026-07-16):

// firmware-slave/servo.cpp
// LX-16A 舵机控制 - 自己实现协议 (不依赖第三方库)
//
// 协议参考: "02+总线舵机通信协议.pdf"
// 帧格式: [0x55][0x55][ID][Length][Cmd][Params...][Checksum]
//   - 校验和 = ~(ID + Length + Cmd + Prm1 + ... + PrmN) 取低 8 位 (取反)
//
// 接线 (1kΩ 电阻方案, 见 README.md):
//   ESP32-S3 GPIO17 (U1TXD) ── 1kΩ ──┬──→ LX-16A 信号线(橙)
//   ESP32-S3 GPIO18 (U1RXD) ─────────┘
//   ESP32-S3 GND ───────────────────→ LX-16A GND(黑)
//   7.4V+ ──────────────────────────→ LX-16A V+(红)
//
// 关键点:
//   - 1kΩ 电阻让 ESP32 TX 在不发送时是"弱驱动", 不会干扰舵机回包
//   - 单线半双工, ESP32 UART 全双工硬件自动处理收发时序
//   - 不需要 DIR 引脚
//   - LX-16A 出厂默认电机卸载 (无力矩), 必须先发 LOAD 命令上电才能动

#include "servo.h"

// ====== 调试开关 ======
// 0 = 不打印每帧指令 (生产模式)
// 1 = 打印每帧指令 (调试用, 100Hz 下串口会爆, 仅低频测试时开)
#define SERVO_DEBUG 0

// 串口 2 给舵机用 (UART2 = GPIO17 TX, GPIO18 RX)
HardwareSerial ServoSerial(2);

// 暂存当前各舵机归一化值, 用于状态打印和调试
static float currentAngles[NUM_SERVOS] = {0};

// ====== 内部: 把 0.0~1.0 映射到 LX-16A 角度单位 (0~1000 = 0~240°) ======
static uint16_t normalizedToLxAngle(float n) {
  if (n < 0.0f) n = 0.0f;
  if (n > 1.0f) n = 1.0f;
  return (uint16_t)(SERVO_ANGLE_MIN + n * (SERVO_ANGLE_MAX - SERVO_ANGLE_MIN));
}

// ====== 内部: 发送原始 LX-16A 帧 (通用) ======
// 协议帧: [0x55][0x55][ID][Length][Cmd][Prm1...PrmN][Checksum]
// Length = 从 Length 自身到 Checksum 的字节数 (含 Length 和 Checksum)
// Checksum = ~(ID + Length + Cmd + Prm1 + ... + PrmN) & 0xFF
static void lx16aSendFrame(uint8_t id, uint8_t cmd, const uint8_t* params, uint8_t paramCount) {
  // 帧总长 = 2(帧头) + 1(ID) + 1(Length) + 1(Cmd) + N(Params) + 1(Checksum)
  // Length = 1(Cmd) + N(Params) + 1(Checksum) + 1(Length自身) = 3 + N
  uint8_t length = 3 + paramCount;
  uint8_t frame[6 + paramCount];  // 2 + 1 + 1 + 1 + N + 1
  uint8_t idx = 0;

  frame[idx++] = 0x55;   // 帧头
  frame[idx++] = 0x55;   // 帧头
  frame[idx++] = id;      // 舵机 ID
  frame[idx++] = length;  // 数据长度
  frame[idx++] = cmd;     // 指令

  for (uint8_t i = 0; i < paramCount; i++) {
    frame[idx++] = params[i];
  }

  // 校验和 = ~(ID + Length + Cmd + Prm1 + ... + PrmN)
  uint8_t sum = 0;
  for (uint8_t i = 2; i < idx; i++) {
    sum += frame[i];
  }
  frame[idx] = ~sum;

  ServoSerial.write(frame, idx + 1);
}

// ====== 内部: 发送 MOVE 命令 (cmd=1) ======
// 参数: angle 0~1000, time 0~30000ms
static void lx16aSendMove(uint8_t id, uint16_t angle, uint16_t timeMs) {
  uint8_t params[4];
  params[0] = angle & 0xFF;         // 角度低字节
  params[1] = (angle >> 8) & 0xFF;  // 角度高字节
  params[2] = timeMs & 0xFF;        // 时间低字节
  params[3] = (timeMs >> 8) & 0xFF; // 时间高字节
  lx16aSendFrame(id, 0x01, params, 4);
}

// ====== 内部: 发送电机上电命令 (cmd=31, LOAD_OR_UNLOAD_WRITE) ======
// 参数: 0=卸载掉电 (无力矩), 1=装载电机 (有力矩)
// LX-16A 出厂默认是 0 (卸载), 必须先发这个才能控制舵机转动
static void lx16aSendLoad(uint8_t id, uint8_t load) {
  uint8_t p = load;
  lx16aSendFrame(id, 0x1F, &p, 1);
}

bool servoSetup() {
  ServoSerial.begin(SERVO_BAUD, SERIAL_8N1, SERVO_RX_PIN, SERVO_TX_PIN);
  delay(50);

  Serial.print("[SERVO] LX-16A init OK (TX=GPIO");
  Serial.print(SERVO_TX_PIN);
  Serial.print(", RX=GPIO");
  Serial.print(SERVO_RX_PIN);
  Serial.print(", baud=");
  Serial.print(SERVO_BAUD);
  Serial.println(")");

  // 给所有舵机上电 (LOAD=1), 否则舵机收到 MOVE 也不会动
  servoPowerOn();

  return true;
}

void servoPowerOn() {
  Serial.println("[SERVO] Powering on all servos (LOAD=1)...");
  for (int i = 0; i < NUM_SERVOS; i++) {
    lx16aSendLoad(SERVO_IDS[i], 1);
    delay(10);  // 每个舵机间隔一点时间, 避免总线冲突
  }
  Serial.println("[SERVO] All servos powered on.");
}

void servoSetNormalized(int servoId, float normalized, uint16_t timeMs) {
  int idx = servoId - 1;
  if (idx >= 0 && idx < NUM_SERVOS) {
    currentAngles[idx] = normalized;
  }

  uint16_t angle = normalizedToLxAngle(normalized);
  lx16aSendMove((uint8_t)servoId, angle, timeMs);

#if SERVO_DEBUG
  Serial.print("[SERVO] ID=");
  Serial.print(servoId);
  Serial.print(" norm=");
  Serial.print(normalized, 2);
  Serial.print(" angle=");
  Serial.println(angle);
#endif
}

void servoSetAll(const float normalized[NUM_SERVOS]) {
  for (int i = 0; i < NUM_SERVOS; i++) {
    servoSetNormalized(SERVO_IDS[i], normalized[i]);
  }
}

void servoSetSafe() {
  servoSetAll(SERVO_SAFE_NORM);
}

void servoPrintStatus() {
  Serial.print("[SERVO STATUS] ");
  for (int i = 0; i < NUM_SERVOS; i++) {
    Serial.print(SERVO_IDS[i]);
    Serial.print(":");
    Serial.print(currentAngles[i], 2);
    Serial.print(" ");
  }
  Serial.println();
}

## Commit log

2026-06-26 初始化项目: 添加 README、参考文档、板子引脚备忘和 git 规则
2026-06-26 添加板子验证测试: 串口心跳、LED、PSRAM
2026-06-26 搭建主从固件框架: 32 字节协议、ESP-NOW 通信、各模块占位实现
2026-06-28 feat(stage1): 弯曲传感器校准值 + 真实数据替换 fake
    硬件: SpectraFlex FLX 55mm + 47kΩ 上拉, 实测 R_flat=19.2kΩ
    校准值: FLEX_RAW_FLAT=1180, FLEX_RAW_BENT=2500
    - config.h: 用实测校准值替换占位 (1500/2800)
    - firmware-master.ino: 删除 fakeFlex (sin 波), 用 flexSensorReadNormalized()
    - 验证: flex[0] 跟随弯曲 ~4000 (平直) → 65535 (180°)
    测试代码: board-test/04_flex_test/ (单独 commit)
    [config.h, firmware-master.ino]
2026-06-28 chore: imu.cpp 加 stub, 阶段 1 跳过 IMU 库依赖
    - BNO055 硬件未到, Adafruit 库未装
    - 用 #if 0 屏蔽真实代码, #else 段提供 stub
    - stub 返回单位四元数 (1,0,0,0), 下游姿态 = 不旋转
    - 阶段 3 拿到 IMU 后: 改 #if 0 为 #if 1, 装 Adafruit_BNO055 库‘’
2026-06-28 fix(wireless): onSend 回调签名适配 Arduino 3.x API
    ESP-IDF 升级后 esp_now_register_send_cb 的回调签名变了:
    - 老: void(*)(const uint8_t* mac, esp_now_send_status_t)
    - 新: void(*)(const wifi_tx_info_t* tx_info, esp_now_send_status_t)
    我们没用 MAC 参数, 只改参数名 (mac → tx_info) + 类型
    函数体不变
    [wireless.cpp]
2026-06-28 test: 弯曲传感器单点测试 (SpectraFlex FLX 55mm)
    阶段 1 调试代码, 验证:
    - 47kΩ 上拉电阻选型正确 (反推 R_flat=19.2kΩ, 符合 datasheet ±20%)
    - 归一化公式 norm = (raw - FLAT) / (BENT - FLAT)
    - 单个弯曲传感器 0.0 → 1.0 范围有效
    用法: 烧录后串口监视器看 ADC + norm, 平直 ~0.02, 弯 180° ~1.00
    [04_flex_test.ino]
2026-06-28 chore: .gitignore 加微信图片规则
    - 临时上传的图片 (微信截图等) 不应该进 git
    - 微信图片_*.jpg 通配符匹配所有微信上传的文件
    - 保留本地文件, 只是不让 git 跟踪
2026-07-07 docs: LX-16A 改用 1kΩ 电阻方案, 释放 GPIO 4
    - README 接线图更新: 转接板方案 → 1kΩ 方案
    - 加原理说明: ESP32 TX 高阻态 + 半双工总线
    - 加多舵机升级路径 (阶段 4 才需要)
    - 引脚备忘同步: 加 GPIO 18 RX, 标记 DIR 已释放
    实测单舵机够用, 节省 30 元控制板成本.
2026-07-07 feat(slave/servo): 自己实现 LX-16A 协议, 不依赖第三方库
    设计决策:
    - GitHub 上 lewanrobot/LewanSoul-LX-16A 仓库 404 了
    - Arduino 库管理器的 HiWonder 库依赖 DIR 引脚 (不匹配 1kΩ 方案)
    - 自己实现 ~80 行协议代码, 反而最简单可控
    改动:
    - servo.cpp: 自己写 lx16aSendMove(), 10 字节协议包
    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
2026-07-07 refactor(master/imu): 用 IMU_HARDWARE_READY 宏替换 #if 0/#else
    之前的代码用 '#if 0' / '#else' 切换, 改的时候要在两个地方都翻, 容易改错.
    现在用一个开关宏, 改 config.h 一个数字就行.
    - config.h: 加 #define IMU_HARDWARE_READY 0 (默认 stub)
    - imu.cpp: #if IMU_HARDWARE_READY ... #else ... #endif
    - 加注释说明: 切到 1 之前要装 Adafruit_BNO055 等库
    阶段 1 保持 0, 阶段 3 拿到硬件后改 1 即可.
    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
2026-07-08 fix(wireless): onReceive 回调签名适配 Arduino 3.x API
    跟 b5c5baf (onSend) 是同一个 ESP-IDF v5 升级带来的连锁问题.
    库 3.x 把 esp_now_recv_cb_t 的第一个参数从 const uint8_t* mac
    改成了 const esp_now_recv_info_t* info (MAC 现在藏在 info->src_addr).
    我们不用 MAC, 只改参数类型和名, 函数体不变.
    真编译验证 (arduino-cli + esp32:esp32 3.3.10) 才发现这个 bug:
    不修的话 slave 端 onReceive 永远不触发, 通信链路静默失败.
    [wireless.cpp]
2026-07-08 feat(wireless): 加 send/rx 双向统计 + seq 校验, 通信质量可观测
    之前的问题:
    - master 调 esp_now_send() 只代表"消息进队列", 不知道对方是否真收到
    - slave 收到帧但 seq 跳了不知道, 丢包看不见
    现在两端每 1 秒打印一次 stats:
    - master: [SEND STATS] ok=98 fail=2 rate=98%
    - slave: [RX STATS] rx=99 lost=1 rate=99%
    - volatile uint32_t: ESP32 单核, 32-bit 读写原子, 不需要互斥锁
    比 mutex 简单太多, 统计差一两次不影响判断
    - seqLostCount 用 uint16_t wrap-safe 减法: master 的 seq 是 uint16_t,
    自然 wrap 65536 次/小时也不需要特殊处理
    - 不重置 seqLastSeen: 重置后会误以为"丢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
    [firmware-master.ino, firmware-slave.ino, wireless.cpp]
2026-07-08 feat(slave): 加断线安全位, 通信超时舵机自动回张开姿势
    场景:
    戴手套时机械手正握东西, master 突然没电/距离过远/电池没电.
    之前 slave 会停在最后位置 = 死死握着, 危险.
    解决:
    通信断了 SAFE_POSITION_TIMEOUT_MS (300ms) → 自动回 SERVO_SAFE_NORM 姿势.
    阶段 1 默认全 0 = 张开手. 阶段 3 拿到 IMU 后可以改成"手掌朝上".
    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
2026-07-08 chore: 把 3D 设计资产和 Fusion 360 AI 助手插件加入版本库
    两个新目录从项目开始就在工作区, 但从来没 commit 过.
    现在软件阶段 1 准备烧录, 把配套的设计/工具资产一起入库.
    openscad/ (15 个文件):
    - 4 个 .scad 源文件: b1_finger / b2_finger / b3_finger / all_fingers
    - 4 个 .stl 生成文件: clone 下来就能直接切片打印
    - 7 个 .png 预览图: 不同角度的渲染图
    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
    [all_fingers.scad, all_fingers.stl, b1_finger.scad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]
2026-07-09 fix(wireless): 修 MAC=0 + lost 算法被 master RST 污染
    两个 bug 都来自阶段 1 验证 (2026-07-09):
    1. MAC=0 问题
    - 现象: 两块 ESP32-S3 启动后 WiFi.macAddress() 返回 00:00:00:00:00:00
    - 原因: WiFi.mode(WIFI_STA) 之后立刻读 MAC, 时序太早 (ESP32 Arduino 3.x 库的通病)
    - 修法: 加 delay(100) 等 STA 模式生效
    - 影响: broadcast 模式不影响 (用 FF:FF:FF:FF:FF:FF),
    阶段 2 改 peer-to-peer 前必须修, 不然没法按 MAC 配对
    2. lost 算法被 master RST 污染
    - 现象: 按 master RST 后 slave 的 lost 数字一下跳到 65187 (虚高)
    - 原因: slave 用 seq 跳变量算 lost, master RST 时 seq wrap 到 0,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
    [wireless.cpp]
2026-07-16 fix(servo): 修舵机不转问题 - 加 LOAD 上电 + 修校验和 + 加 timeMs
    根因: LX-16A 出厂默认电机卸载 (无力矩), 原代码只发 MOVE 没发 LOAD;
    校验和注释写错 (不取反), 代码实际正确但 timeMs=0 导致舵机不响应。
    - servo.cpp: 加通用帧发送 lx16aSendFrame, 加 LOAD 上电命令, 修注释
    - servo.h: 加 servoPowerOn(), servoSetNormalized 默认 timeMs=50
    - slave ino: 恢复无线控制主循环, 加安全模式滞后 (10帧), 加状态监控
    - master ino: 减少 framePrint 频率 (10→100帧/次) 避免串口阻塞
    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
    [firmware-master.ino, firmware-slave.ino, servo.cpp]
2026-07-16 docs: 更新阶段1验证进度, 2/3 已通过
2026-07-16 feat(master): 加原始 ADC 打印, 方便弯曲传感器校准
2026-07-16 fix(master): 校准弯曲传感器, 实测平直1330/弯曲2800
2026-07-16 docs: 阶段1验证全部通过 (3/3)
2026-07-16 docs: 加 AGENTS.md 项目指南
2026-07-17 更新3D手指模型: 墙厚改为2mm, 关节孔改为⌀5.3, M2螺丝孔改为⌀2.0, 新增销钉可视化和配合测试件, 导出STL
    [all_fingers.scad, b1_finger.scad, b1_finger.stl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]
2026-07-17 feat: 阶段2完成 - ESP-NOW广播升级为peer-to-peer
    改动用:
    - Master: config.h 新增 SLAVE_MAC 配置项, 填入 slave 真实 MAC
    - Master: wireless.cpp 用 SLAVE_MAC 替代硬编码广播地址
    - Slave: wireless.cpp 收到首帧自动提取 master MAC 注册 peer
    - README: 阶段2标记完成, 更新验证标准为 ESP-NOW 相关
    - 修复: esp_now_add_peer 挪到主循环执行, 避免回调阻塞导致断线
    [config.h, wireless.cpp]
